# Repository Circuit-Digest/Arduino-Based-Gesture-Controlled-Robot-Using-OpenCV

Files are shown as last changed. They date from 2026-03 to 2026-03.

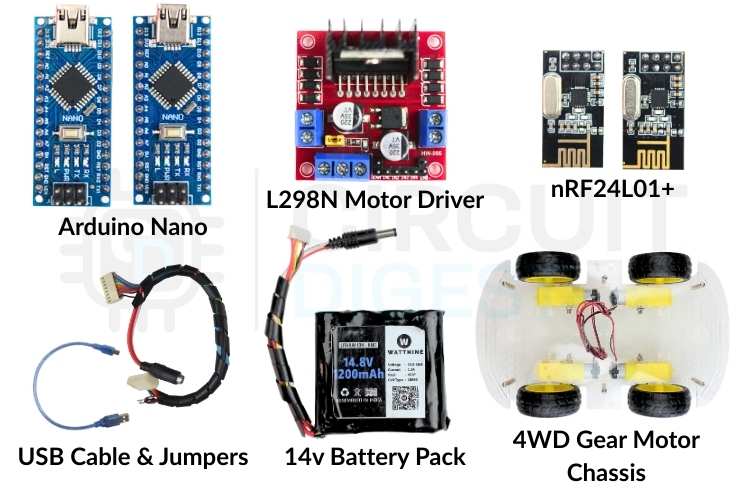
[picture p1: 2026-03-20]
Components-Used-In-Gesture-Controlled-Robot.jpg

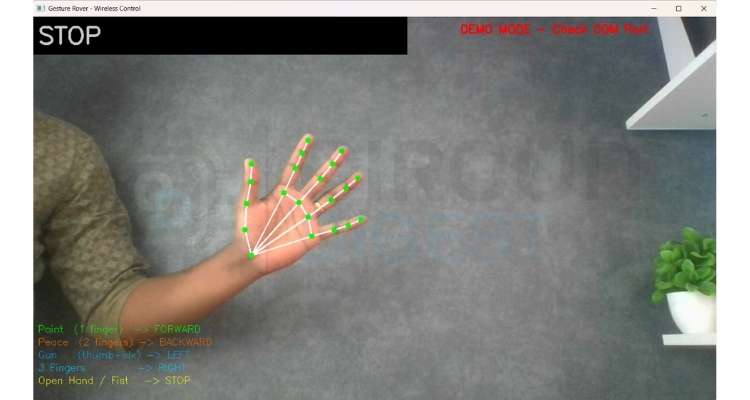
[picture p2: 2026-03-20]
Hand-Gesture-Landmarks.jpg

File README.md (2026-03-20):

# Arduino-Based Gesture-Controlled Robot Using OpenCV

Gesture-controlled robotics replaces traditional buttons and joysticks with natural hand movements, improving user interaction and reducing mechanical dependency on physical controllers. Sensors capture motion, convert it into digital data, and translate that data into robot movement in real time.

This project demonstrates a gesture-controlled robot using a **laptop webcam**, **OpenCV**, and **MediaPipe** for real-time hand detection. Hand gestures captured by the camera control the robot's direction, while an **nRF24L01** radio module transmits commands wirelessly from a transmitter Arduino Nano to a receiver Arduino Nano mounted on the rover. The **L298N motor driver** on the receiver side converts those commands into motor actions.

The design focuses on clarity, reliability, and low-cost components that makers can easily source and assemble. This setup forms a strong foundation for advanced human-machine interaction projects.

## Table of Contents

- [System Overview and Working Principle](#system-overview-and-working-principle)
- [Hardware Components Used](#hardware-components-used)
- [nRF24L01 Wireless Module Overview](#nrf24l01-wireless-module-overview)
- [Pin Connections](#pin-connections)
- [OpenCV and Python Installation](#opencv-and-python-installation)
- [How OpenCV and MediaPipe Work Together](#how-opencv-and-mediapipe-work-together)
- [Gesture Detection](#gesture-detection)
- [Wireless Communication Using nRF24L01](#wireless-communication-using-nrf24l01)
- [Source Code Explanation](#source-code-explanation)
- [Testing and Output](#testing-and-output)
- [Applications](#applications)
- [Future Enhancements](#future-enhancements)
- [FAQs](#faqs)
- [License](#license)

## System Overview and Working Principle

This gesture-controlled robot operates using a **three-part wireless control architecture**:

1. A **Python program** running on the laptop captures hand gestures via the webcam, recognizes them using OpenCV and MediaPipe, and sends serial commands to the transmitter Arduino Nano.
2. The **transmitter** forwards those commands wirelessly to the receiver Nano on the rover.
3. The **receiver Nano** drives the motors through the L298N motor driver.

### Data Flow

```
Webcam → Python (OpenCV + MediaPipe) → USB Serial → TX Arduino Nano → nRF24L01 (wireless) → RX Arduino Nano → L298N Motor Driver → DC Motors
```

The Python application processes each camera frame in real time. MediaPipe detects **21 landmarks** on the hand, and the program uses the relative positions of fingertips and knuckles to determine which fingers are raised. Each finger pattern maps to a specific movement command such as Forward, Backward, Left, Right, or Stop.

After determining the required action, Python sends a **single-character command** over USB serial to the transmitter Nano. The transmitter packages it and sends it wirelessly using the nRF24L01 module. The receiver Nano stays in constant listening mode and executes the motor routine as soon as a valid command arrives.

## Hardware Components Used

| Component | Quantity | Purpose |
|---|---|---|
| Arduino Nano | 2 | Transmitter & Receiver microcontrollers |
| nRF24L01 Wireless Module | 2 | Wireless command transmission |
| L298N Motor Driver | 1 | DC motor speed & direction control |
| 4-Wheel DC Gear Motor Chassis | 1 | Robot body with motors |
| Laptop with Webcam | 1 | Gesture capture & processing |
| External 12V Battery Pack | 1 | Motor power supply |
| Jumper Wires and Breadboard | — | Circuit connections |

## nRF24L01 Wireless Module Overview

The nRF24L01 is a low-power wireless transceiver designed for short-range communication. It operates in the **2.4 GHz ISM band** and supports fast, reliable data transfer between microcontrollers. The module uses **SPI communication**, which allows the Arduino Nano to send and receive data with precise timing and control.

In this project, the nRF24L01 works in a **point-to-point configuration**. One module stays in transmit mode on the controller side, while the other stays in receive mode on the robot side.

## Pin Connections

### nRF24L01 → Arduino Nano (Same for Both TX and RX)

| nRF24L01 Pin | Arduino Nano Pin |
|---|---|
| GND | GND |
| VCC | 3.3V |
| CSN | D8 |
| CE | D9 |
| MOSI | D11 |
| MISO | D12 |
| SCK | D13 |

### Transmitter Connections

The transmitter unit connects to the laptop via USB. It receives single-character serial commands from the Python gesture script and forwards them wirelessly to the rover using the nRF24L01 module.

**Data Flow:**
```
Laptop (Python) → USB Serial → Arduino Nano TX → nRF24L01 → Rover
```

### Receiver → L298N Motor Driver Connections

The receiver unit sits on the rover and connects to the L298N motor driver.

| L298N Pin | Arduino Nano Pin | Function |
|---|---|---|
| IN1 | D2 | Motor A Direction 1 |
| IN2 | D3 | Motor A Direction 2 |
| IN3 | D4 | Motor B Direction 1 |
| IN4 | D6 | Motor B Direction 2 |
| ENA | D5 (PWM) | Motor A Speed Control |
| ENB | D10 (PWM) | Motor B Speed Control |
| GND | GND | Common Ground |
| +12V | External Battery | Motor Power |
| +5V | Nano VIN | Logic Power |

---

## OpenCV and Python Installation

### Step 1: Install Python

Download **Python 3.10 or 3.11** from [python.org](https://python.org). During installation, check the option **"Add Python to PATH"**.

### Step 2: Create Project Folder and Virtual Environment

Open Command Prompt and run:

```bash
mkdir hand_gesture_project
cd hand_gesture_project
python -m venv venv
venv\Scripts\activate
```

> **Note:** The `(venv)` prefix in the terminal confirms the environment is active.

### Step 3: Install Required Libraries

```bash
pip install opencv-python mediapipe pyserial
```

| Library | Purpose |
|---|---|
| `opencv-python` | Camera capture and image frame processing |
| `mediapipe` | Google hand landmark detection (21 points per hand) |
| `pyserial` | USB serial communication with Arduino TX Nano |

### Step 4: Download the MediaPipe Hand Landmarker Model

On the first run, the Python script **automatically downloads** the `hand_landmarker.task` model file (~9MB) from Google. An internet connection is required only for this one-time download.

## How OpenCV and MediaPipe Work Together

OpenCV captures frames from the laptop webcam as NumPy arrays in BGR format. Each frame is flipped horizontally for a natural mirror effect, then converted to RGB before being passed to MediaPipe. MediaPipe processes the frame and returns the X, Y coordinates of **21 hand landmarks**.

| Landmark Index | Body Part |
|---|---|
| 0 | Wrist |
| 4 | Thumb Tip |
| 8 | Index Finger Tip |
| 12 | Middle Finger Tip |
| 16 | Ring Finger Tip |
| 20 | Pinky Tip |

## Gesture Detection

The Python script detects hand gestures by analyzing the positions of 21 hand landmarks. A finger is considered **raised** when its tip landmark has a lower Y coordinate than its middle knuckle landmark on screen (since Y increases downward in image coordinates). The thumb uses the **X axis** for comparison since it moves horizontally.

### Gesture Mapping

| Gesture | Fingers Up | Command | Rover Action |
|---|---|---|---|
| Point (index only) | `[0,1,0,0,0]` | `F` | Move Forward |
| Peace / V sign | `[0,1,1,0,0]` | `B` | Move Backward |
| Gun (thumb + index) | `[1,1,0,0,0]` | `L` | Turn Left |
| Three fingers | `[1,1,1,0,0]` | `R` | Turn Right |
| Open hand | `[1,1,1,1,1]` | `S` | Stop |
| Fist | `[0,0,0,0,0]` | `S` | Stop |

> Commands are throttled to send at most once every **150 milliseconds** to prevent flooding the serial port. If no hand is detected, a **Stop** command is sent automatically to keep the rover safe.

## Wireless Communication Using nRF24L01

Both modules are configured with the same pipe address, channel, data rate, and power level:

- **Pipe Address:** `"00001"`
- **Power Level:** `RF24_PA_LOW` — improves stability at short range and reduces power consumption
- **Channel:** 108 — avoids interference from common WiFi bands
- **Payload:** Single character (`F`, `B`, `L`, `R`, or `S`) in a 2-byte packet

## Source Code Explanation

### 📁 Project Structure

```
├── Source Code/
│   ├── Arduino/
│   │   ├── Transmitter/
│   │   │   └── Transmitter.ino      # TX Nano code
│   │   └── Receiver/
│   │       └── Receiver.ino          # RX Nano code (rover)
│   └── Python/
│       └── hand_gesture_project/
│           ├── gesture.py            # Python gesture detection script
│           └── hand_landmarker.task  # MediaPipe model (auto-downloaded)
├── Images/
└── README.md
```

### Python Gesture Detection Script (`gesture.py`)

This script runs on the laptop. It captures webcam frames, detects hand landmarks using MediaPipe, classifies the gesture, and sends the command character over serial to the TX Nano.

**Serial Connection:**

```python
try:
    arduino = serial.Serial(SERIAL_PORT, BAUD_RATE, timeout=1)
    time.sleep(2)
except Exception as e:
    arduino = None
```

The two-second sleep is important because Arduinos reboot the moment a serial connection is made. If the connection fails, it sets `arduino` to `None` and keeps running in demo mode.

**Automatic Model Download:**

```python
if not os.path.exists(MODEL_PATH):
    urllib.request.urlretrieve(
        'https://storage.googleapis.com/mediapipe-models/...',
        MODEL_PATH)
```

**Finger Detection Logic:**

```python
fingers.append(1 if landmarks[4].x < landmarks[3].x else 0)  # Thumb (horizontal)
for tip in TIP_IDS[1:]:
    fingers.append(1 if landmarks[tip].y < landmarks[tip-2].y else 0)  # Other fingers (vertical)
```

**Gesture Classification:**

```python
if f == [0,1,0,0,0]: return ('FORWARD',  'F', (0,255,0))
if f == [0,1,1,0,0]: return ('BACKWARD', 'B', (0,0,255))
if f == [1,1,0,0,0]: return ('LEFT',     'L', (255,165,0))
if f == [1,1,1,0,0]: return ('RIGHT',    'R', (255,200,0))
if f == [1,1,1,1,1]: return ('STOP',     'S', (0,255,255))
```

---

### Arduino Transmitter Code (`Transmitter.ino`)

This program runs on the TX Nano connected to the laptop via USB. It reads single-character serial commands from Python and transmits them wirelessly.

```cpp
#include <SPI.h>
#include <RF24.h>

RF24 radio(9, 8);  // CE=D9, CSN=D8
const byte address[6] = "00001";
```

- `radio.begin()` initializes the nRF24 module with error checking
- `openWritingPipe(address)` sets the transmission address
- `setPALevel(RF24_PA_LOW)` sets low power for short-range use
- `stopListening()` sets the module to transmitter mode

Valid commands (`F`, `B`, `L`, `R`, `S`) are packaged into a 2-byte payload and sent wirelessly via `radio.write()`.

### Arduino Receiver Code (`Receiver.ino`)

This sketch runs on the Nano mounted on the rover. It listens for wireless commands and drives the motors at **50% speed** (`motorSpeed = 128`) through the L298N motor driver.

```cpp
#define IN1 2    // Motor A Direction 1
#define IN2 3    // Motor A Direction 2
#define IN3 4    // Motor B Direction 1
#define IN4 6    // Motor B Direction 2
#define ENA 5    // Motor A Speed (PWM)
#define ENB 10   // Motor B Speed (PWM)

int motorSpeed = 128;  // 50% of 255
```

Motor functions:

| Function | Motor A (IN1/IN2) | Motor B (IN3/IN4) | Result |
|---|---|---|---|
| `moveForward()` | HIGH/LOW | HIGH/LOW | Both motors forward |
| `moveBackward()` | LOW/HIGH | LOW/HIGH | Both motors backward |
| `turnLeft()` | LOW/HIGH | HIGH/LOW | Left motor back, right forward |
| `turnRight()` | HIGH/LOW | LOW/HIGH | Left motor forward, right back |
| `stopMotors()` | LOW/LOW | LOW/LOW | All motors stop (speed = 0) |

## Testing and Output

Follow this sequence for a reliable first test:

1. **Upload TX code** to the Nano connected to the laptop. Open Serial Monitor (9600 baud) and type `F` — confirm it prints `Sent: F`.
2. **Connect the RX Nano** to the laptop separately. Open its Serial Monitor and check it prints `Received: F` when TX sends.
3. **Close ALL Serial Monitors** before running Python.
4. **Mount the RX Nano** on the rover and connect to L298N. Power rover with a 12V battery.
5. **Run** `python gesture.py` on the laptop. Show hand gestures to the camera and observe the rover movement.

> ⚠️ **Important:** Python and Arduino IDE Serial Monitor cannot share the same COM port simultaneously. Always close the Serial Monitor before running the Python script.

## Applications

- Remote-controlled robotic vehicles and surveillance rovers
- Assistive robots for basic mobility tasks
- Educational platforms for learning computer vision and embedded systems
- Human-machine interface experimentation
- Contactless control systems for hazardous environments
- Prototype control models for industrial robotics and automation

## Future Enhancements

- Add **two-hand gesture support** for simultaneous speed and direction control
- Implement **variable motor speed** based on finger count or hand distance from the camera
- Add **obstacle detection** using ultrasonic or IR sensors on the rover
- Replace character commands with **structured data packets** for higher efficiency
- Use **external antenna nRF24L01** modules to improve wireless range
- Add a **real-time video stream** from a camera mounted on the rover
- Train a **custom gesture classifier** using scikit-learn for more gesture variety

## FAQs

<details>
<summary><strong>Why does the nRF24L01 require 3.3V power?</strong></summary>
<br>
The nRF24L01 uses internal RF circuitry that operates strictly at 3.3V. Supplying 5V damages the internal transceiver permanently. Even brief exposure to higher voltage causes unstable transmission or complete module failure. A regulated 3.3V supply with proper grounding ensures stable wireless performance.
</details>

<details>
<summary><strong>Why is the Serial Monitor closed before running Python?</strong></summary>
<br>
Python and Arduino IDE Serial Monitor cannot share the same COM port simultaneously. Whichever opens first locks the port, blocking the other. Always close the Serial Monitor before running the Python script, or it will fail to connect with a <code>Permission Denied</code> error.
</details>

<details>
<summary><strong>Why is motor speed limited to 50%?</strong></summary>
<br>
The L298N and DC gear motors can draw more than 5A at full speed under load, which risks overheating the motor driver and draining the battery rapidly. Setting <code>motorSpeed</code> to 128 out of 255 limits PWM duty cycle to 50%, keeping current draw within safe limits while still providing sufficient torque.
</details>

<details>
<summary><strong>What is the maximum operating range of the system?</strong></summary>
<br>
Using <code>RF24_PA_LOW</code>, the reliable range is typically 10 to 30 meters indoors, depending on obstacles and interference. Switching to <code>RF24_PA_HIGH</code> with a decoupling capacitor across the nRF24 VCC and GND pins can extend the range further.
</details>

<details>
<summary><strong>Can this work without a virtual environment?</strong></summary>
<br>
Yes, but a virtual environment is strongly recommended. It prevents library version conflicts between projects. If using PowerShell, activate with <code>venv\Scripts\Activate.ps1</code> after enabling script execution, or switch to Command Prompt and use <code>venv\Scripts\activate</code> instead.
</details>

<details>
<summary><strong>What if the rover moves in the wrong direction?</strong></summary>
<br>
Swap the <code>IN1</code> and <code>IN2</code> definitions in the RX Arduino code for the affected motor side. Alternatively, physically swap the two motor wires going into the L298N output terminals for that channel. No hardware damage occurs from reversed motor polarity.
</details>

---

## License

This project is open-source and available under the [MIT License](LICENSE).

---

<p align="center">
  <b>If you found this project helpful, give it a ⭐ on GitHub!</b>
</p>

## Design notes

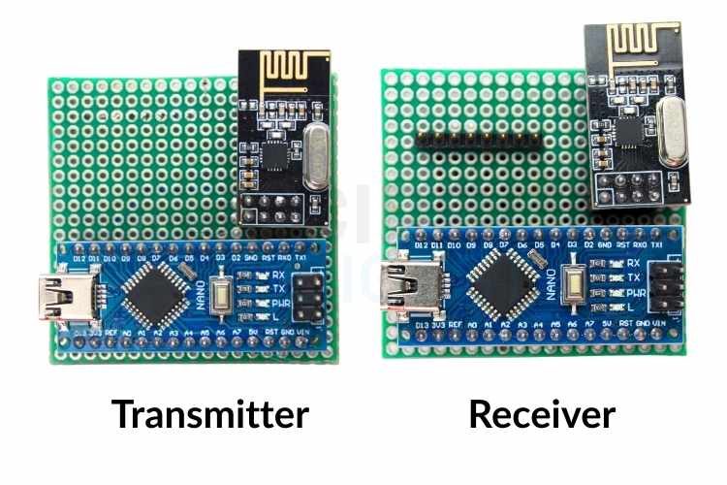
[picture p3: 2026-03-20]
Gesture-Controlled-Robot-TX-And-RX-PCB.jpg

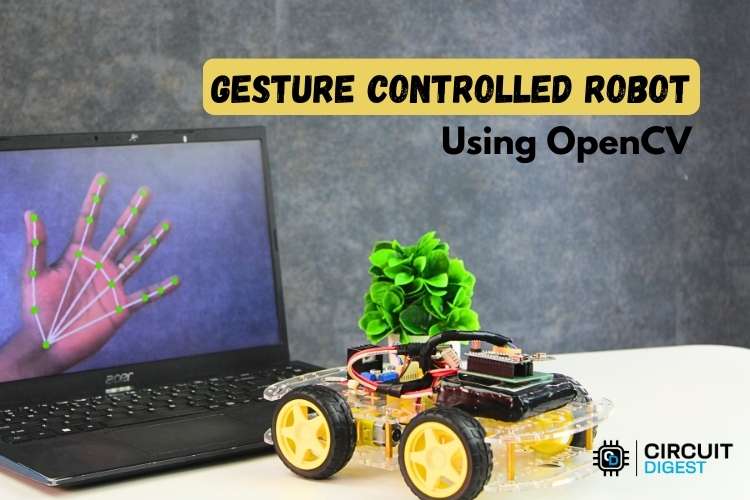
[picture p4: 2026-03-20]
Gesture-Controlled-Robot.jpg

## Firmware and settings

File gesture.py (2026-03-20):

import cv2
import mediapipe as mp
import os
import urllib.request
import serial
import time
from mediapipe.tasks import python
from mediapipe.tasks.python import vision

# ── CONFIG ───────────────────────────────────────────────────────
SERIAL_PORT  = "COM4"
BAUD_RATE    = 9600
CMD_INTERVAL = 0.15

# ── Connect to TX Arduino ────────────────────────────────────────
try:
    arduino = serial.Serial(SERIAL_PORT, BAUD_RATE, timeout=1)
    time.sleep(2)
    print(f"Connected to TX Nano on {SERIAL_PORT}")
except Exception as e:
    print(f"Serial connection failed: {e}")
    print("Running in DEMO MODE")
    arduino = None

def send_command(cmd):
    if arduino and arduino.is_open:
        arduino.write((cmd + "\n").encode())

# ── Download MediaPipe model ─────────────────────────────────────
MODEL_PATH = "hand_landmarker.task"
if not os.path.exists(MODEL_PATH):
    print("Downloading model (~9MB)...")
    urllib.request.urlretrieve(
        "https://storage.googleapis.com/mediapipe-models/hand_landmarker/hand_landmarker/float16/1/hand_landmarker.task",
        MODEL_PATH
    )
    print("Download complete!")

# ── Finger detection ─────────────────────────────────────────────
TIP_IDS = [4, 8, 12, 16, 20]

def fingers_up(landmarks):
    fingers = []
    fingers.append(1 if landmarks[4].x < landmarks[3].x else 0)
    for tip in TIP_IDS[1:]:
        fingers.append(1 if landmarks[tip].y < landmarks[tip - 2].y else 0)
    return fingers

def classify_gesture(f):
    if f == [0, 1, 0, 0, 0]: return ("FORWARD",  "F", (0, 255, 0))
    if f == [0, 1, 1, 0, 0]: return ("BACKWARD", "B", (0, 0, 255))
    if f == [1, 1, 0, 0, 0]: return ("LEFT",     "L", (255, 165, 0))
    if f == [1, 1, 1, 0, 0]: return ("RIGHT",    "R", (255, 200, 0))
    if f == [1, 1, 1, 1, 1]: return ("STOP",     "S", (0, 255, 255))
    if f == [0, 0, 0, 0, 0]: return ("STOP",     "S", (0, 255, 255))
    return                           ("STOP",     "S", (200, 200, 200))

# ── Draw hand landmarks ──────────────────────────────────────────
CONNECTIONS = [
    (0,1),(1,2),(2,3),(3,4),
    (0,5),(5,6),(6,7),(7,8),
    (0,9),(9,10),(10,11),(11,12),
    (0,13),(13,14),(14,15),(15,16),
    (0,17),(17,18),(18,19),(19,20),
    (5,9),(9,13),(13,17)
]

def draw_landmarks(frame, landmarks, h, w):
    pts = [(int(lm.x * w), int(lm.y * h)) for lm in landmarks]
    for a, b in CONNECTIONS:
        cv2.line(frame, pts[a], pts[b], (255, 255, 255), 2)
    for pt in pts:
        cv2.circle(frame, pt, 5, (0, 255, 0), -1)

# ── MediaPipe setup ──────────────────────────────────────────────
options = vision.HandLandmarkerOptions(
    base_options=python.BaseOptions(model_asset_path=MODEL_PATH),
    num_hands=1,
    min_hand_detection_confidence=0.5,
    min_hand_presence_confidence=0.5,
    min_tracking_confidence=0.5
)
detector = vision.HandLandmarker.create_from_options(options)

# ── Webcam ───────────────────────────────────────────────────────
cap = cv2.VideoCapture(0)
cap.set(cv2.CAP_PROP_FRAME_WIDTH, 1280)
cap.set(cv2.CAP_PROP_FRAME_HEIGHT, 720)
print("Camera started. Press 'q' to quit.")

last_cmd      = ""
last_cmd_time = 0

while True:
    ret, frame = cap.read()
    if not ret:
        break

    frame = cv2.flip(frame, 1)
    h, w, _ = frame.shape

    rgb      = cv2.cvtColor(frame, cv2.COLOR_BGR2RGB)
    mp_image = mp.Image(image_format=mp.ImageFormat.SRGB, data=rgb)
    result   = detector.detect(mp_image)

    label, cmd, color = "No Hand - STOP", "S", (200, 200, 200)

    if result.hand_landmarks:
        for landmarks in result.hand_landmarks:
            draw_landmarks(frame, landmarks, h, w)
            f = fingers_up(landmarks)
            label, cmd, color = classify_gesture(f)

    # Throttled send
    now = time.time()
    if cmd != last_cmd or (now - last_cmd_time) > CMD_INTERVAL:
        send_command(cmd)
        last_cmd      = cmd
        last_cmd_time = now

    # ── HUD ──────────────────────────────────────────────────────
    cv2.rectangle(frame, (0, 0), (700, 70), (0, 0, 0), -1)
    cv2.putText(frame, label, (10, 50),
                cv2.FONT_HERSHEY_SIMPLEX, 1.5, color, 3)

    legend = [
        ("Point  (1 finger)  -> FORWARD",  (0, 255, 0)),
        ("Peace  (2 fingers) -> BACKWARD", (0, 100, 255)),
        ("Gun    (thumb+idx) -> LEFT",     (255, 165, 0)),
        ("3 Fingers          -> RIGHT",    (255, 200, 0)),
        ("Open Hand / Fist   -> STOP",     (0, 255, 255)),
    ]
    for i, (text, c) in enumerate(legend):
        cv2.putText(frame, text, (10, 590 + i * 24),
                    cv2.FONT_HERSHEY_SIMPLEX, 0.6, c, 1)

    status       = "Wireless TX: Connected | COM4" if arduino else "DEMO MODE - Check COM Port"
    status_color = (0, 255, 0) if arduino else (0, 0, 255)
    cv2.putText(frame, status, (w - 480, 30),
                cv2.FONT_HERSHEY_SIMPLEX, 0.7, status_color, 2)

    cv2.imshow("Gesture Rover - Wireless Control", frame)
    if cv2.waitKey(1) & 0xFF == ord('q'):
        send_command('S')
        break

cap.release()
cv2.destroyAllWindows()
if arduino:
    arduino.close()

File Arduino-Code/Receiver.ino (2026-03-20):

#include <SPI.h>
#include <RF24.h>

RF24 radio(9, 8);
const byte address[6] = "00001";

#define IN1 2
#define IN2 3
#define IN3 4
#define IN4 6
#define ENA 5
#define ENB 10

int motorSpeed = 80;

void setup() {
  pinMode(IN1, OUTPUT);
  pinMode(IN2, OUTPUT);
  pinMode(IN3, OUTPUT);
  pinMode(IN4, OUTPUT);
  pinMode(ENA, OUTPUT);
  pinMode(ENB, OUTPUT);

  stopMotors();

  radio.begin();
  radio.openReadingPipe(0, address);
  radio.setPALevel(RF24_PA_LOW);
  radio.startListening();

  Serial.begin(9600);
  Serial.println("RX Ready");
}

void loop() {
  if (radio.available()) {
    char payload[2] = "";
    radio.read(&payload, sizeof(payload));
    char cmd = payload[0];

    Serial.print("Received: ");
    Serial.println(cmd);

    if      (cmd == 'F') moveForward();
    else if (cmd == 'B') moveBackward();
    else if (cmd == 'L') turnLeft();
    else if (cmd == 'R') turnRight();
    else if (cmd == 'S') stopMotors();
  }
}

void moveForward() {
  analogWrite(ENA, motorSpeed);
  analogWrite(ENB, motorSpeed);
  digitalWrite(IN1, HIGH);
  digitalWrite(IN2, LOW);
  digitalWrite(IN3, HIGH);
  digitalWrite(IN4, LOW);
}

void moveBackward() {
  analogWrite(ENA, motorSpeed);
  analogWrite(ENB, motorSpeed);
  digitalWrite(IN1, LOW);
  digitalWrite(IN2, HIGH);
  digitalWrite(IN3, LOW);
  digitalWrite(IN4, HIGH);
}

void turnLeft() {
  analogWrite(ENA, motorSpeed);
  analogWrite(ENB, motorSpeed);
  digitalWrite(IN1, LOW);
  digitalWrite(IN2, HIGH);
  digitalWrite(IN3, HIGH);
  digitalWrite(IN4, LOW);
}

void turnRight() {
  analogWrite(ENA, motorSpeed);
  analogWrite(ENB, motorSpeed);
  digitalWrite(IN1, HIGH);
  digitalWrite(IN2, LOW);
  digitalWrite(IN3, LOW);
  digitalWrite(IN4, HIGH);
}

void stopMotors() {
  analogWrite(ENA, 0);
  analogWrite(ENB, 0);
  digitalWrite(IN1, LOW);
  digitalWrite(IN2, LOW);
  digitalWrite(IN3, LOW);
  digitalWrite(IN4, LOW);
}
